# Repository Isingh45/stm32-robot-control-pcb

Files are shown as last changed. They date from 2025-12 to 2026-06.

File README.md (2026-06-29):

# MecaArm Robotic Platform

## Overview

MecaArm is an STM32-based mobile robotic platform developed as the Senior Design Capstone project for **CMPE 492 / CMPE 493** at **California State University, East Bay**.

The platform integrates omnidirectional Mecanum-wheel locomotion, a multi-servo robotic arm, a custom four-layer PCB, embedded firmware, Bluetooth communication, and a mobile application into a complete robotics system.

The project demonstrates end-to-end embedded systems engineering by combining custom hardware design, firmware development, wireless communication, power electronics, and system-level validation.

---

## Technologies

* STM32F429VET6
* ESP32-WROOM-32
* C
* STM32 HAL
* STM32CubeMX
* Bluetooth (UART)
* PWM Motor Control
* Fusion 360 Electronics
* MIT App Inventor
* RT7258 Buck Regulators
* TB6612FNG Motor Drivers

---

## System Architecture

```text
MIT App Inventor Mobile App
             │
        Bluetooth
             │
      ESP32-WROOM-32
             │
      UART (115200 baud)
             │
      STM32F429VET6
      ┌───────────────┐
      │               │
      ▼               ▼
DC Motor Drivers   Servo Control
(TB6612FNG)        (PWM Timers)
      │               │
      ▼               ▼
Mecanum Drive     Robotic Arm
```

---

## Features

* **Custom Four-Layer PCB:** Designed a custom four-layer PCB centered around the STM32F429VET6 microcontroller with dedicated power distribution, motor drivers, communication interfaces, and debugging support.

* **Omnidirectional Mecanum Drive:** Controls four independently driven Mecanum wheels using PWM motor control and dual TB6612FNG motor drivers for omnidirectional robot movement.

* **Robotic Arm Control:** Controls a multi-servo robotic arm using STM32 hardware timers and PWM signals for coordinated actuator movement.

* **Bluetooth Wireless Communication:** Uses an ESP32 as a Bluetooth-to-UART bridge, allowing a custom MIT App Inventor mobile application to wirelessly control the robot.

* **Embedded Firmware:** Developed STM32 firmware using STM32 HAL to manage motor control, servo control, UART communication, and command processing.

* **Multi-Rail Power Architecture:** Designed dedicated power rails for motors, auxiliary peripherals, and logic circuitry to improve electrical stability and isolate high-current motor loads from sensitive electronics.

* **System Integration and Validation:** Successfully demonstrated integrated hardware, firmware, Bluetooth communication, mobile application control, robotic locomotion, and robotic arm operation.

---

## Repository Structure

```text
Documentation/
├── Final Project Report
└── Final Presentation

Hardware/
├── PCB Schematic
├── PCB Layout
├── Fusion 360 Design
├── Bill of Materials
└── Power Budget

Firmware/
├── STM32 Firmware
└── ESP32 Bluetooth Bridge

Mobile-App/
└── MIT App Inventor Application

Validation/
└── System Demonstration Video
```

---

## What I Learned

* Designing custom embedded hardware using a four-layer PCB.
* Developing embedded firmware with STM32 HAL and hardware timers.
* Implementing Bluetooth communication between mobile devices and embedded systems.
* Integrating power electronics, embedded software, wireless communication, and robotic actuators.
* Performing hardware bring-up, debugging, validation, and complete system integration.

---

## Future Improvements

* Add wheel encoder feedback for closed-loop motor control.
* Implement inverse kinematics for robotic arm positioning.
* Integrate ROS 2 for higher-level robot control.
* Add onboard sensors for autonomous navigation.
* Expand the platform with additional perception modules.

---

## Authors

* Inderpal Singh
* Sukhpinder Singh
* Feranmi Falodun
* Pierreline Jacob

**California State University, East Bay**

**CMPE 492 / CMPE 493 – Senior Design Capstone (2025–2026)**

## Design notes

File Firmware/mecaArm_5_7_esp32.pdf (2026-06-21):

#include "BluetoothSerial.h"

#define RXp2 16

#define TXp2 17

BluetoothSerial SerialBT;
String device_name = "ESP32-BT";

void setup() {
SerialBT.begin(device_name); Serial2.begin(115200, SERIAL_8N1, RXp2, TXp2); }

void loop() {
while (SerialBT.available()) {
uint8_t c = SerialBT.read();

// Forward everything from the app to STM32 Serial2.write(c);
}
}

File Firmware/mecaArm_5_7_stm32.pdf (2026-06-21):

/* ============================================================ * STM32F429VIT6 — Combined 4-Wheel Robot + 6-DOF Arm Controller
* ============================================================ *
* MODE SWITCHING:
* Send 'M' to toggle between Robot mode and Arm mode.
* On startup the board is in ROBOT mode.
*
* ── ROBOT MODE (4-wheel drive via TB6612FNG) ──────────────── * Commands (ASCII bytes from ESP32 app):
* F Move forward
* B Move backward
* L Turn left
* R Turn right
* S Stop
*
* Motor PWM: TIM1 (PA8=CH1, PA9=CH2, PA10=CH3, PA11=CH4) * Direction GPIOs:
* Motor 4: PD4 / PD5
* Motor 3: PD2 / PD3
* Motor 1A: PC4 / PC5
* Motor 1B: PD0 / PD1
* STBY: PC0 (HIGH = drivers enabled)
*
* ── ARM MODE (6-DOF servo arm via Hiwonder 500–2500 µs) ───── * Commands (numeric bytes from ESP32 app):
* 1/2 Base rotate right/left
* 3/4 Shoulder up/down
* 5/6 Elbow up/down
* 7/8 Wrist rotate CW/CCW
* 9/10 Wrist pitch up/down * 11/12 Gripper open/close
* 13 | Save current position
* 14 | Reset / stop sequence
* 15 | Run saved sequence
* 16 | Pause (send 15 to resume, 14 to stop)
* H | Home all servos to 1500 µs
* 101–249 Set servo speed (value / 10 = ms per step)
*
* Servo GPIO / Timer mapping:
* ┌────────────┬───────┬───────────┬───────────────────────┐
* │ Servo | │ GPIO │ Timer | │ PCB connector | │
* ├────────────┼───────┼───────────┼───────────────────────┤ * │ Base │ PD12 │ TIM4_CH1 │ LS2 pad pin1=SIGNAL │

* │ Shoulder │ PD13 │ TIM4_CH2 │ LS1 pad pin1=SIGNAL │ * │ Elbow │ PA1 │ TIM2_CH2 │ PH1 hdr pin1=SIGNAL │ * │ Wrist R │ PD14 │ TIM4_CH3 │ JP8 pad pin1=SIGNAL │
* │ Wrist P │ PB15 │ TIM12_CH2 │ LS3 pad pin1=SIGNAL │
* │ Gripper │ PA2 │ TIM2_CH3 │ PH2 hdr pin1=SIGNAL │
* └────────────┴───────┴───────────┴───────────────────────┘ *
* BLUETOOTH: UART7 (PE7=RX, PE8=TX) — 115200 baud
* ============================================================ */

#include "main.h"

#include <stdlib.h>

#include <string.h>

#include <stdio.h>

/* ── Timer / UART handles ─────────────────────────────────── */
TIM_HandleTypeDef htim1; /* Robot motor PWM — TIM1 CH1-CH4 | */
TIM_HandleTypeDef htim2; /* Servo 50 Hz | — PA1(CH2) PA2(CH3) | */
TIM_HandleTypeDef htim4; /* Servo 50 Hz | — PD12(CH1) PD13(CH2) PD14(CH3) */
TIM_HandleTypeDef htim12; /* Servo 50 Hz | — PB15(CH2) | */
UART_HandleTypeDef huart7; /* Bluetooth 115200 baud | */

/* ── Robot defines ───────────────────────────────────────────*/ #define MOTOR_SPEED 750 /* 75 % duty (max = MOTOR_MAX) */
#define MOTOR_MAX 1000 /* matches TIM1 Period = 999 */

/* ── Arm defines ─────────────────────────────────────────────*/ #define SERVO_MIN_US 500
#define SERVO_MAX_US 2500

#define SERVO_MID_US 1500

#define NUM_SERVOS | 6

#define MAX_STEPS | 50

#define SERVO_STEP_SIZE 10

#define S_BASE 0 /* PD12 TIM4_CH1 LS2 pad */ #define S_SHOULDER 1 /* PD13 TIM4_CH2 LS1 pad */ #define S_ELBOW 2 /* PA1 TIM2_CH2 PH1 hdr */ #define S_WRIST_R 3 /* PD14 TIM4_CH3 JP8 pad */

#define S_WRIST_P 4 /* PB15 TIM12_CH2 LS3 pad */

#define S_GRIPPER 5 /* PA2 TIM2_CH3 PH2 hdr */

/* ── Global state ────────────────────────────────────────────*/ typedef enum { MODE_ROBOT = 0, MODE_ARM = 1 } ControlMode;
ControlMode currentMode = MODE_ROBOT;

/* Arm globals */
int32_t servoPos[NUM_SERVOS] = {
SERVO_MID_US, SERVO_MID_US, SERVO_MID_US, SERVO_MID_US, SERVO_MID_US, SERVO_MID_US };
int32_t savedSteps[MAX_STEPS][NUM_SERVOS];
int | stepCount | = 0;
int | speedDelay | = 20;
uint8_t servoPwmStarted = 0;

/* ── Prototypes ──────────────────────────────────────────────*/ void SystemClock_Config(void);
static void MX_GPIO_Init(void);
static void MX_TIM1_Init(void);
static void MX_TIM2_Init(void); static void MX_TIM4_Init(void); static void MX_TIM12_Init(void);
static void MX_UART7_Init(void);

/* Robot */
void Move_Robot(int16_t m4, int16_t m3, int16_t m1a, int16_t m1b); void Stop_Robot(void);

/* Arm */
void Servo_EnablePWM(void);
void Servo_WritePulse(uint8_t id, int32_t pulseUs); void Servo_Step(uint8_t id, int8_t direction);
void Servo_Home(void);
void Run_Sequence(void);

/* Shared */
void UART_Print(const char *msg);
void Print_Mode(void);

/* ============================================================ * MAIN
* ============================================================ */ int main(void)
{
HAL_Init();
SystemClock_Config();

MX_GPIO_Init();

MX_TIM1_Init();
MX_TIM2_Init();
MX_TIM4_Init();
MX_TIM12_Init();
MX_UART7_Init();

/* Start robot motor PWM channels */ HAL_TIM_PWM_Start(&htim1, TIM_CHANNEL_1); HAL_TIM_PWM_Start(&htim1, TIM_CHANNEL_2); HAL_TIM_PWM_Start(&htim1, TIM_CHANNEL_3); HAL_TIM_PWM_Start(&htim1, TIM_CHANNEL_4);

/* Enable TB6612FNG drivers: STBY = PC0 HIGH */ HAL_GPIO_WritePin(GPIOC, GPIO_PIN_0, GPIO_PIN_SET); HAL_Delay(100);

Stop_Robot();

UART_Print("=== MecaArm Controller Ready ===\r\n");
UART_Print("Wheels: F/B/L/R/S | Arm: numeric bytes 1-15 | 0=arm stop | H=home\r\n");

uint8_t rx = 0;
uint8_t armM = 0;
char dbg[64];

while (1)
{
if (HAL_UART_Receive(&huart7, &rx, 1, 10) == HAL_OK) {

sprintf(dbg, "RX: %c (%d)\r\n",
(rx >= 32 && rx < 127) ? rx : '.', rx);
UART_Print(dbg);

HAL_GPIO_TogglePin(GPIOA, GPIO_PIN_5);

/* ===================================================== * ARM STOP: app sends byte 0 on button release
* ===================================================== */ if (rx == 0)
{
armM = 0;
goto loop_end;
}

/* ===================================================== * WHEEL COMMANDS: ASCII bytes from app
* ===================================================== */
if (rx == 'F')
{
Move_Robot(MOTOR_SPEED, MOTOR_SPEED, MOTOR_SPEED, MOTOR_SPEED); armM = 0;
UART_Print("MOVE FORWARD\r\n");
goto loop_end;
}

if (rx == 'B')
{
Move_Robot(-MOTOR_SPEED, -MOTOR_SPEED, -MOTOR_SPEED, -MOTOR_SPEED); armM = 0;
UART_Print("MOVE BACKWARD\r\n");
goto loop_end;
}

if (rx == 'R')
{
Move_Robot(-MOTOR_SPEED, -MOTOR_SPEED, MOTOR_SPEED, MOTOR_SPEED); armM = 0;
UART_Print("TURN RIGHT\r\n");
goto loop_end;
}

if (rx == 'L')
{
Move_Robot(MOTOR_SPEED, MOTOR_SPEED, -MOTOR_SPEED, -MOTOR_SPEED); armM = 0;
UART_Print("TURN LEFT\r\n");
goto loop_end;
}

if (rx == 'S')
{
Stop_Robot();
armM = 0;
UART_Print("STOP\r\n");
goto loop_end;
}

/* ===================================================== * ARM HOME: ASCII H
* ===================================================== */ if (rx == 'H')
{
Servo_EnablePWM();
Servo_Home();
armM = 0;
UART_Print("Servos homed.\r\n");
goto loop_end;
}

/* ===================================================== * SAVE POSITION: raw byte 13
* ===================================================== */ if (rx == 13)
{
Servo_EnablePWM();

if (stepCount < MAX_STEPS)
{
for (int i = 0; i < NUM_SERVOS; i++) savedSteps[stepCount][i] = servoPos[i];

stepCount++;
UART_Print("Position saved.\r\n");
}
else
{
UART_Print("Sequence full.\r\n"); }

armM = 0;
goto loop_end;
}

/* ===================================================== * RESET SEQUENCE: raw byte 14
* ===================================================== */ if (rx == 14)
{
stepCount = 0;
armM = 0;
Stop_Robot();

UART_Print("Sequence reset.\r\n");
goto loop_end;
}

/* ===================================================== * RUN SEQUENCE: raw byte 15
* ===================================================== */ if (rx == 15)
{
Servo_EnablePWM();
Run_Sequence();
armM = 0;
goto loop_end;
}

/* ===================================================== * PAUSE: raw byte 16 or 18 depending on app
* Your app seems to send 18, so accept both.
* ===================================================== */ if (rx == 16 || rx == 18)
{
armM = 0;
UART_Print("Pause command received.\r\n");
goto loop_end;
}

/* ===================================================== * SPEED: raw bytes 101-249
* ===================================================== */ if (rx >= 101 && rx <= 249)
{
speedDelay = rx / 10;
sprintf(dbg, "Speed set: %d ms/step\r\n", speedDelay); UART_Print(dbg);
armM = 0;
goto loop_end;
}

/* ===================================================== * ARM MOVEMENT: raw numeric bytes 1-12
* ===================================================== */ if (rx >= 1 && rx <= 12)
{
armM = rx;

Servo_EnablePWM();
goto loop_end;
}
}

loop_end:

/* Continuous arm movement while app button is held */ switch (armM)
{
case 1:
Servo_Step(S_BASE, +1);
HAL_Delay(speedDelay);
break;

case 2:
Servo_Step(S_BASE, -1);
HAL_Delay(speedDelay);
break;

case 3:
Servo_Step(S_SHOULDER, +1); HAL_Delay(speedDelay);
break;

case 4:
Servo_Step(S_SHOULDER, -1); HAL_Delay(speedDelay);
break;

case 5:
Servo_Step(S_ELBOW, +1);
HAL_Delay(speedDelay);
break;

case 6:
Servo_Step(S_ELBOW, -1);
HAL_Delay(speedDelay);
break;

case 7:
Servo_Step(S_WRIST_R, +1); HAL_Delay(speedDelay);
break;

case 8:
Servo_Step(S_WRIST_R, -1); HAL_Delay(speedDelay);
break;

case 9:
Servo_Step(S_WRIST_P, +1); HAL_Delay(speedDelay);
break;

case 10:
Servo_Step(S_WRIST_P, -1); HAL_Delay(speedDelay);
break;

case 11:
Servo_Step(S_GRIPPER, +1); HAL_Delay(speedDelay);
break;

case 12:
Servo_Step(S_GRIPPER, -1); HAL_Delay(speedDelay);
break;

default:
break;
}
}
}

/* ============================================================ * ROBOT MOTOR CONTROL
* ============================================================ */ void Move_Robot(int16_t m4, int16_t m3, int16_t m1a, int16_t m1b)
{
/* Motor 4 — PD4/PD5 direction, TIM1_CH1 speed */
HAL_GPIO_WritePin(GPIOD, GPIO_PIN_4, (m4 >= 0) ? GPIO_PIN_SET : GPIO_PIN_RESET);
HAL_GPIO_WritePin(GPIOD, GPIO_PIN_5, (m4 >= 0) ? GPIO_PIN_RESET : GPIO_PIN_SET);
__HAL_TIM_SET_COMPARE(&htim1, TIM_CHANNEL_1, (uint32_t)abs(m4));

/* Motor 3 — PD2/PD3 direction, TIM1_CH2 speed */ HAL_GPIO_WritePin(GPIOD, GPIO_PIN_2, (m3 >= 0) ? GPIO_PIN_SET : GPIO_PIN_RESET);
HAL_GPIO_WritePin(GPIOD, GPIO_PIN_3, (m3 >= 0) ? GPIO_PIN_RESET : GPIO_PIN_SET);
__HAL_TIM_SET_COMPARE(&htim1, TIM_CHANNEL_2, (uint32_t)abs(m3));

/* Motor 1A — PC4/PC5 direction, TIM1_CH3 speed */ HAL_GPIO_WritePin(GPIOC, GPIO_PIN_4, (m1a >= 0) ? GPIO_PIN_SET : GPIO_PIN_RESET);
HAL_GPIO_WritePin(GPIOC, GPIO_PIN_5, (m1a >= 0) ? GPIO_PIN_RESET : GPIO_PIN_SET);
__HAL_TIM_SET_COMPARE(&htim1, TIM_CHANNEL_3, (uint32_t)abs(m1a));

/* Motor 1B — PD0/PD1 direction, TIM1_CH4 speed */ HAL_GPIO_WritePin(GPIOD, GPIO_PIN_0, (m1b >= 0) ? GPIO_PIN_SET : GPIO_PIN_RESET);
HAL_GPIO_WritePin(GPIOD, GPIO_PIN_1, (m1b >= 0) ? GPIO_PIN_RESET : GPIO_PIN_SET);
__HAL_TIM_SET_COMPARE(&htim1, TIM_CHANNEL_4, (uint32_t)abs(m1b)); }

void Stop_Robot(void)
{
Move_Robot(0, 0, 0, 0);
}

/* ============================================================ * SERVO / ARM CONTROL
* ============================================================ */ void Servo_EnablePWM(void)
{
if (servoPwmStarted) return;

HAL_TIM_PWM_Start(&htim2, TIM_CHANNEL_2); /* PA1 Elbow */ HAL_TIM_PWM_Start(&htim2, TIM_CHANNEL_3); /* PA2 Gripper */ HAL_TIM_PWM_Start(&htim4, TIM_CHANNEL_1); /* PD12 Base */ HAL_TIM_PWM_Start(&htim4, TIM_CHANNEL_2); /* PD13 Shoulder */ HAL_TIM_PWM_Start(&htim4, TIM_CHANNEL_3); /* PD14 Wrist R */ HAL_TIM_PWM_Start(&htim12, TIM_CHANNEL_2); /* PB15 Wrist P */

servoPwmStarted = 1;
}

/**
* @brief Write pulse width in microseconds to one servo.
* | Timer clock = 1 MHz (PSC=15 at 16 MHz HSI)
* | → 1 tick = 1 µs → CCR = pulseUs directly.
* | Clamped to Hiwonder range 500–2500 µs.
*/
void Servo_WritePulse(uint8_t id, int32_t pulseUs) {
if (id >= NUM_SERVOS) return;
Servo_EnablePWM();

if (pulseUs < SERVO_MIN_US) pulseUs = SERVO_MIN_US; if (pulseUs > SERVO_MAX_US) pulseUs = SERVO_MAX_US; servoPos[id] = pulseUs;

switch (id)
{
case S_BASE: __HAL_TIM_SET_COMPARE(&htim4, TIM_CHANNEL_1, (uint32_t)pulseUs); break;
case S_SHOULDER: __HAL_TIM_SET_COMPARE(&htim4, TIM_CHANNEL_2, (uint32_t)pulseUs); break;
case S_ELBOW: __HAL_TIM_SET_COMPARE(&htim2, TIM_CHANNEL_2, (uint32_t)pulseUs); break;
case S_WRIST_R: __HAL_TIM_SET_COMPARE(&htim4, TIM_CHANNEL_3, (uint32_t)pulseUs); break;
case S_WRIST_P: __HAL_TIM_SET_COMPARE(&htim12, TIM_CHANNEL_2, (uint32_t)pulseUs); break;
case S_GRIPPER: __HAL_TIM_SET_COMPARE(&htim2, TIM_CHANNEL_3, (uint32_t)pulseUs); break;
default: break;
}
}

void Servo_Step(uint8_t id, int8_t direction)
{
Servo_WritePulse(id, servoPos[id] + (direction * SERVO_STEP_SIZE)); }

void Servo_Home(void)
{
Servo_WritePulse(S_BASE, SERVO_MID_US); Servo_WritePulse(S_SHOULDER, SERVO_MID_US); Servo_WritePulse(S_ELBOW, SERVO_MID_US); Servo_WritePulse(S_WRIST_R, SERVO_MID_US);

Servo_WritePulse(S_WRIST_P, SERVO_MID_US); Servo_WritePulse(S_GRIPPER, SERVO_MID_US); }

/**
* @brief Play back saved positions.
* Byte 14 = stop, byte 16 = pause (byte 15 resumes). */
void Run_Sequence(void)
{
if (stepCount < 2)
{
UART_Print("Need at least 2 saved positions.\r\n"); return;
}

UART_Print("Running sequence. Send 14 to stop.\r\n");

uint8_t rx = 0;
uint8_t running = 1;

while (running)
{
for (int i = 0; i < stepCount - 1 && running; i++)
{
if (HAL_UART_Receive(&huart7, &rx, 1, 1) == HAL_OK) {
if (rx == 14) { running = 0; break; }
if (rx == 16)
{
UART_Print("Paused. Send 15 to resume.\r\n"); while (rx != 15 && rx != 14) HAL_UART_Receive(&huart7, &rx, 1, 100); if (rx == 14) { running = 0; break; } UART_Print("Resumed.\r\n");
}
}

for (uint8_t s = 0; s < NUM_SERVOS && running; s++) {
int32_t from = savedSteps[i][s];
int32_t to = savedSteps[i + 1][s];
if (from == to) continue;

int8_t dir = (to > from) ? 1 : -1;
for (int32_t pos = from; pos != to; pos += dir) {
Servo_WritePulse(s, pos);
HAL_Delay(speedDelay);
if (HAL_UART_Receive(&huart7, &rx, 1, 1) == HAL_OK && rx == 14) { running = 0; break; }
}
}
}
}

UART_Print("Sequence stopped.\r\n");
}

/* ============================================================ * SHARED HELPERS
* ============================================================ */ void UART_Print(const char *msg)
{
HAL_UART_Transmit(&huart7, (uint8_t *)msg, strlen(msg), 100);
}

void Print_Mode(void)
{
if (currentMode == MODE_ROBOT)
UART_Print("-- ROBOT MODE -- (F/B/L/R/S | 'M' to switch)\r\n");
else
UART_Print("-- ARM MODE -- (1-12=move 13=save 14=reset 15=run H=home | 'M' to
switch)\r\n");
}

/**
* @brief System Clock Configuration * @retval None
*/
void SystemClock_Config(void)
{
RCC_OscInitTypeDef RCC_OscInitStruct = {0}; RCC_ClkInitTypeDef RCC_ClkInitStruct = {0};

/** Configure the main internal regulator output voltage */
__HAL_RCC_PWR_CLK_ENABLE();

__HAL_PWR_VOLTAGESCALING_CONFIG(PWR_REGULATOR_VOLTAGE_SCALE3);

/** Initializes the RCC Oscillators according to the specified parameters
* in the RCC_OscInitTypeDef structure.
*/
RCC_OscInitStruct.OscillatorType = RCC_OSCILLATORTYPE_HSI; RCC_OscInitStruct.HSIState = RCC_HSI_ON; RCC_OscInitStruct.HSICalibrationValue = RCC_HSICALIBRATION_DEFAULT; RCC_OscInitStruct.PLL.PLLState = RCC_PLL_NONE;
if (HAL_RCC_OscConfig(&RCC_OscInitStruct) != HAL_OK)
{
Error_Handler();
}

/** Initializes the CPU, AHB and APB buses clocks
*/
RCC_ClkInitStruct.ClockType = RCC_CLOCKTYPE_HCLK|RCC_CLOCKTYPE_SYSCLK |RCC_CLOCKTYPE_PCLK1|RCC_CLOCKTYPE_PCLK2; RCC_ClkInitStruct.SYSCLKSource = RCC_SYSCLKSOURCE_HSI; RCC_ClkInitStruct.AHBCLKDivider = RCC_SYSCLK_DIV1; RCC_ClkInitStruct.APB1CLKDivider = RCC_HCLK_DIV1; RCC_ClkInitStruct.APB2CLKDivider = RCC_HCLK_DIV1;

if (HAL_RCC_ClockConfig(&RCC_ClkInitStruct, FLASH_LATENCY_0) != HAL_OK) {
Error_Handler();
}
}

/**
* @brief TIM1 Initialization Function * @param None
* @retval None
*/
static void MX_TIM1_Init(void)
{

/* USER CODE BEGIN TIM1_Init 0 */

/* USER CODE END TIM1_Init 0 */

TIM_ClockConfigTypeDef sClockSourceConfig = {0}; TIM_MasterConfigTypeDef sMasterConfig = {0}; TIM_OC_InitTypeDef sConfigOC = {0};

TIM_BreakDeadTimeConfigTypeDef sBreakDeadTimeConfig = {0};

/* USER CODE BEGIN TIM1_Init 1 */

/* USER CODE END TIM1_Init 1 */
htim1.Instance = TIM1;
htim1.Init.Prescaler = 179;
htim1.Init.CounterMode = TIM_COUNTERMODE_UP; htim1.Init.Period = 999;
htim1.Init.ClockDivision = TIM_CLOCKDIVISION_DIV1; htim1.Init.RepetitionCounter = 0;
htim1.Init.AutoReloadPreload = TIM_AUTORELOAD_PRELOAD_ENABLE; if (HAL_TIM_Base_Init(&htim1) != HAL_OK)
{
Error_Handler();
}
sClockSourceConfig.ClockSource = TIM_CLOCKSOURCE_INTERNAL;
if (HAL_TIM_ConfigClockSource(&htim1, &sClockSourceConfig) != HAL_OK) {
Error_Handler();
}
if (HAL_TIM_PWM_Init(&htim1) != HAL_OK) {
Error_Handler();
}
sMasterConfig.MasterOutputTrigger = TIM_TRGO_RESET; sMasterConfig.MasterSlaveMode = TIM_MASTERSLAVEMODE_DISABLE;
if (HAL_TIMEx_MasterConfigSynchronization(&htim1, &sMasterConfig) != HAL_OK) {
Error_Handler();
}
sConfigOC.OCMode = TIM_OCMODE_PWM1; sConfigOC.Pulse = 0;
sConfigOC.OCPolarity = TIM_OCPOLARITY_HIGH; sConfigOC.OCNPolarity = TIM_OCNPOLARITY_HIGH; sConfigOC.OCFastMode = TIM_OCFAST_DISABLE;
sConfigOC.OCIdleState = TIM_OCIDLESTATE_RESET;
sConfigOC.OCNIdleState = TIM_OCNIDLESTATE_RESET;
if (HAL_TIM_PWM_ConfigChannel(&htim1, &sConfigOC, TIM_CHANNEL_1) != HAL_OK) {
Error_Handler();
}
if (HAL_TIM_PWM_ConfigChannel(&htim1, &sConfigOC, TIM_CHANNEL_2) != HAL_OK) {

Error_Handler();
}
if (HAL_TIM_PWM_ConfigChannel(&htim1, &sConfigOC, TIM_CHANNEL_3) != HAL_OK) {
Error_Handler();
}
if (HAL_TIM_PWM_ConfigChannel(&htim1, &sConfigOC, TIM_CHANNEL_4) != HAL_OK) {
Error_Handler();
}
sBreakDeadTimeConfig.OffStateRunMode = TIM_OSSR_DISABLE; sBreakDeadTimeConfig.OffStateIDLEMode = TIM_OSSI_DISABLE; sBreakDeadTimeConfig.LockLevel = TIM_LOCKLEVEL_OFF; sBreakDeadTimeConfig.DeadTime = 0;
sBreakDeadTimeConfig.BreakState = TIM_BREAK_DISABLE; sBreakDeadTimeConfig.BreakPolarity = TIM_BREAKPOLARITY_HIGH; sBreakDeadTimeConfig.AutomaticOutput = TIM_AUTOMATICOUTPUT_DISABLE; if (HAL_TIMEx_ConfigBreakDeadTime(&htim1, &sBreakDeadTimeConfig) != HAL_OK) {
Error_Handler();
}
/* USER CODE BEGIN TIM1_Init 2 */

/* USER CODE END TIM1_Init 2 */ HAL_TIM_MspPostInit(&htim1);

}

/**
* @brief TIM2 Initialization Function * @param None
* @retval None
*/
static void MX_TIM2_Init(void)
{

/* USER CODE BEGIN TIM2_Init 0 */

/* USER CODE END TIM2_Init 0 */

TIM_MasterConfigTypeDef sMasterConfig = {0}; TIM_OC_InitTypeDef sConfigOC = {0};

/* USER CODE BEGIN TIM2_Init 1 */

/* USER CODE END TIM2_Init 1 */
htim2.Instance = TIM2;
htim2.Init.Prescaler = 15;
htim2.Init.CounterMode = TIM_COUNTERMODE_UP; htim2.Init.Period = 19999;
htim2.Init.ClockDivision = TIM_CLOCKDIVISION_DIV1; htim2.Init.AutoReloadPreload = TIM_AUTORELOAD_PRELOAD_DISABLE; if (HAL_TIM_PWM_Init(&htim2) != HAL_OK)
{
Error_Handler();
}
sMasterConfig.MasterOutputTrigger = TIM_TRGO_RESET; sMasterConfig.MasterSlaveMode = TIM_MASTERSLAVEMODE_DISABLE;
if (HAL_TIMEx_MasterConfigSynchronization(&htim2, &sMasterConfig) != HAL_OK) {
Error_Handler();
}
sConfigOC.OCMode = TIM_OCMODE_PWM1; sConfigOC.Pulse = 0;
sConfigOC.OCPolarity = TIM_OCPOLARITY_HIGH;
sConfigOC.OCFastMode = TIM_OCFAST_DISABLE;
if (HAL_TIM_PWM_ConfigChannel(&htim2, &sConfigOC, TIM_CHANNEL_2) != HAL_OK) {
Error_Handler();
}
if (HAL_TIM_PWM_ConfigChannel(&htim2, &sConfigOC, TIM_CHANNEL_3) != HAL_OK) {
Error_Handler();
}
/* USER CODE BEGIN TIM2_Init 2 */

/* USER CODE END TIM2_Init 2 */ HAL_TIM_MspPostInit(&htim2);

}

/**
* @brief TIM4 Initialization Function * @param None
* @retval None
*/
static void MX_TIM4_Init(void) {

/* USER CODE BEGIN TIM4_Init 0 */

/* USER CODE END TIM4_Init 0 */

TIM_ClockConfigTypeDef sClockSourceConfig = {0}; TIM_MasterConfigTypeDef sMasterConfig = {0}; TIM_OC_InitTypeDef sConfigOC = {0};

/* USER CODE BEGIN TIM4_Init 1 */

/* USER CODE END TIM4_Init 1 */
htim4.Instance = TIM4;
htim4.Init.Prescaler = 15;
htim4.Init.CounterMode = TIM_COUNTERMODE_UP; htim4.Init.Period = 19999;
htim4.Init.ClockDivision = TIM_CLOCKDIVISION_DIV1; htim4.Init.AutoReloadPreload = TIM_AUTORELOAD_PRELOAD_DISABLE; if (HAL_TIM_Base_Init(&htim4) != HAL_OK)
{
Error_Handler();
}
sClockSourceConfig.ClockSource = TIM_CLOCKSOURCE_INTERNAL;
if (HAL_TIM_ConfigClockSource(&htim4, &sClockSourceConfig) != HAL_OK) {
Error_Handler();
}
if (HAL_TIM_PWM_Init(&htim4) != HAL_OK) {
Error_Handler();
}
sMasterConfig.MasterOutputTrigger = TIM_TRGO_RESET; sMasterConfig.MasterSlaveMode = TIM_MASTERSLAVEMODE_DISABLE;
if (HAL_TIMEx_MasterConfigSynchronization(&htim4, &sMasterConfig) != HAL_OK) {
Error_Handler();
}
sConfigOC.OCMode = TIM_OCMODE_PWM1; sConfigOC.Pulse = 0;
sConfigOC.OCPolarity = TIM_OCPOLARITY_HIGH;
sConfigOC.OCFastMode = TIM_OCFAST_DISABLE;
if (HAL_TIM_PWM_ConfigChannel(&htim4, &sConfigOC, TIM_CHANNEL_1) != HAL_OK) {
Error_Handler();

}
if (HAL_TIM_PWM_ConfigChannel(&htim4, &sConfigOC, TIM_CHANNEL_2) != HAL_OK) {
Error_Handler();
}
if (HAL_TIM_PWM_ConfigChannel(&htim4, &sConfigOC, TIM_CHANNEL_3) != HAL_OK) {
Error_Handler();
}
/* USER CODE BEGIN TIM4_Init 2 */

/* USER CODE END TIM4_Init 2 */ HAL_TIM_MspPostInit(&htim4);

}

/**
* @brief TIM12 Initialization Function * @param None
* @retval None
*/
static void MX_TIM12_Init(void)
{

/* USER CODE BEGIN TIM12_Init 0 */

/* USER CODE END TIM12_Init 0 */

TIM_OC_InitTypeDef sConfigOC = {0};

/* USER CODE BEGIN TIM12_Init 1 */

/* USER CODE END TIM12_Init 1 */ htim12.Instance = TIM12;
htim12.Init.Prescaler = 15;
htim12.Init.CounterMode = TIM_COUNTERMODE_UP; htim12.Init.Period = 19999;
htim12.Init.ClockDivision = TIM_CLOCKDIVISION_DIV1; htim12.Init.AutoReloadPreload = TIM_AUTORELOAD_PRELOAD_DISABLE; if (HAL_TIM_PWM_Init(&htim12) != HAL_OK)
{
Error_Handler();
}
sConfigOC.OCMode = TIM_OCMODE_PWM1;

sConfigOC.Pulse = 0;
sConfigOC.OCPolarity = TIM_OCPOLARITY_HIGH;
sConfigOC.OCFastMode = TIM_OCFAST_DISABLE;
if (HAL_TIM_PWM_ConfigChannel(&htim12, &sConfigOC, TIM_CHANNEL_2) != HAL_OK) {
Error_Handler();
}
/* USER CODE BEGIN TIM12_Init 2 */

/* USER CODE END TIM12_Init 2 */ HAL_TIM_MspPostInit(&htim12);

}

/**
* @brief UART7 Initialization Function * @param None
* @retval None
*/
static void MX_UART7_Init(void)
{

/* USER CODE BEGIN UART7_Init 0 */

/* USER CODE END UART7_Init 0 */

/* USER CODE BEGIN UART7_Init 1 */

/* USER CODE END UART7_Init 1 */ huart7.Instance = UART7;
huart7.Init.BaudRate = 115200; huart7.Init.WordLength = UART_WORDLENGTH_8B; huart7.Init.StopBits = UART_STOPBITS_1; huart7.Init.Parity = UART_PARITY_NONE; huart7.Init.Mode = UART_MODE_TX_RX; huart7.Init.HwFlowCtl = UART_HWCONTROL_NONE; huart7.Init.OverSampling = UART_OVERSAMPLING_16; if (HAL_UART_Init(&huart7) != HAL_OK)
{
Error_Handler();
}
/* USER CODE BEGIN UART7_Init 2 */

/* USER CODE END UART7_Init 2 */

}

/**
* @brief GPIO Initialization Function * @param None
* @retval None
*/
static void MX_GPIO_Init(void)
{
GPIO_InitTypeDef GPIO_InitStruct = {0}; /* USER CODE BEGIN MX_GPIO_Init_1 */

/* USER CODE END MX_GPIO_Init_1 */

/* GPIO Ports Clock Enable */ __HAL_RCC_GPIOC_CLK_ENABLE(); __HAL_RCC_GPIOA_CLK_ENABLE(); __HAL_RCC_GPIOE_CLK_ENABLE(); __HAL_RCC_GPIOB_CLK_ENABLE();
__HAL_RCC_GPIOD_CLK_ENABLE();

/*Configure GPIO pin Output Level */
HAL_GPIO_WritePin(GPIOC, GPIO_PIN_0|GPIO_PIN_4|GPIO_PIN_5, GPIO_PIN_RESET);

/*Configure GPIO pin Output Level */
HAL_GPIO_WritePin(GPIOA, GPIO_PIN_5, GPIO_PIN_RESET);

/*Configure GPIO pin Output Level */
HAL_GPIO_WritePin(GPIOD, GPIO_PIN_0|GPIO_PIN_1|GPIO_PIN_2|GPIO_PIN_3 |GPIO_PIN_4|GPIO_PIN_5, GPIO_PIN_RESET);

/*Configure GPIO pins : PC0 PC4 PC5 */
GPIO_InitStruct.Pin = GPIO_PIN_0|GPIO_PIN_4|GPIO_PIN_5; GPIO_InitStruct.Mode = GPIO_MODE_OUTPUT_PP; GPIO_InitStruct.Pull = GPIO_NOPULL; GPIO_InitStruct.Speed = GPIO_SPEED_FREQ_LOW; HAL_GPIO_Init(GPIOC, &GPIO_InitStruct);

/*Configure GPIO pin : PA5 */
GPIO_InitStruct.Pin = GPIO_PIN_5; GPIO_InitStruct.Mode = GPIO_MODE_OUTPUT_PP; GPIO_InitStruct.Pull = GPIO_NOPULL; GPIO_InitStruct.Speed = GPIO_SPEED_FREQ_LOW;

HAL_GPIO_Init(GPIOA, &GPIO_InitStruct);

/*Configure GPIO pins : PD0 PD1 PD2 PD3
PD4 PD5 */
GPIO_InitStruct.Pin = GPIO_PIN_0|GPIO_PIN_1|GPIO_PIN_2|GPIO_PIN_3 |GPIO_PIN_4|GPIO_PIN_5;
GPIO_InitStruct.Mode = GPIO_MODE_OUTPUT_PP; GPIO_InitStruct.Pull = GPIO_NOPULL;
GPIO_InitStruct.Speed = GPIO_SPEED_FREQ_LOW; HAL_GPIO_Init(GPIOD, &GPIO_InitStruct);

/* USER CODE BEGIN MX_GPIO_Init_2 */

/* USER CODE END MX_GPIO_Init_2 */ }

/* USER CODE BEGIN 4 */

/* USER CODE END 4 */

/**
* @brief This function is executed in case of error occurrence. * @retval None
*/
void Error_Handler(void)
{
/* USER CODE BEGIN Error_Handler_Debug */
/* User can add his own implementation to report the HAL error return state */ __disable_irq();
while (1)
{
}
/* USER CODE END Error_Handler_Debug */ }
#ifdef USE_FULL_ASSERT

/**
* @brief Reports the name of the source file and the source line number * where the assert_param error has occurred.
* @param file: pointer to the source file name
* @param line: assert_param error line source number
* @retval None
*/
void assert_failed(uint8_t *file, uint32_t line)
{

/* USER CODE BEGIN 6 */
/* User can add his own implementation to report the file name and line number, ex: printf("Wrong parameters value: file %s on line %d\r\n", file, line) */
/* USER CODE END 6 */
}
#endif /* USE_FULL_ASSERT */

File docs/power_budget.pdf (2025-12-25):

Electrical Inputs | Temperature | Power + Efficiency | Noise / Ripple Design | Passive Components | Protection / Documentation Component | Pins | Function / Role | Source Rail Output Rail | V_in (V) | V_out (V) | I_typ (mA) | I_peak in (mA) trace_in | trace_in | I_peak out (mA) | trace_out Duty (%) | P_out (mW) | η (%) | P_in (mW) | P_loss (mW) | Noise Sensitivity Allowed Ripple/Noise (mVpp) | Est. Ripple (mVpp) | Post-Filter Type | Local Capacitance (F) | Resistors (Ω) | Inductance (H) | Protection | Notes | Datasheet | Design | Distributor Zeee 2S Lipo Battery 2200mAh 7.4V
50C Shorty Pack Battery with XT60 Connector | Main power source | BAT_7.4V | - | - | 7.4 V | - | 150 mil | 948 mil | - | - | - | - | - | - | - | - | - | - | - | - | -

Two 3.7 V 1800 mAh
Li-ion cells in series. Typical 1C continuous discharge, 2C peak. | you need connector on
your board | Hiwonder

LFD-218 servo

Signal Wire Positive pole of power supply Ground Wire | High-torque PWM digital servo for arm joints | BAT_7.4V | - | 7.4V | - | 100 mA | 75 mil | 181 mil | - | - | - | - | - | - | -

Full-metal digital servo for arm joints. No-load 100 mA. Locked-rotor (stall) 2.4–3 A. Works from 2S

Li-ion/LiPo rail. PWM
signal from MCU, high
current drawn from battery
rail. | Hiwonder
LD-1501MG servo | White WireSignal input Red WireConnect to 7.4 V

Black WireConnect to ground

High-precision PWM digital servo
(used for base / shoulder / elbow
joints) | BAT_7.4V | - | 7.4V | - | 100 mA | 75 mil | 181 mil | - | - | - | - | - | - | -

Metal-gear servo. Working
voltage 6–8.4 V. No-load
100 mA. Stall 2.4–3 A. PWM control. Used for precise joints. | Hiwonder Buck 5V(RT7258) | Step-down buck: BAT_7.4V →
Buck_5V rail for 5 V loads | BAT_7.4V | Buck_5V | BAT_7.4V | 5 V | - | 60 mil | 256 mil | 60 mil | 380 mil | - | 25.75 W | 90 % | 28.611 W | 2.861W

TT Motor 1

1 pin for power another to ground | Drive motor (Mecanum wheel) | Buck_5V | - | 5V | - | 100 mA (assumpton) | - | 51 mil | - | - | - | - | - | - | -

Ratio 1:42, Weight 30 g, Speed 150 RPM, Size

63×22×19 mm, Works with TurboPi/MasterPi/GoGoPi/ 4WD

TT Motor 2 | Drive motor (Mecanum wheel) | Buck_5V | - | 5V | - | - | - | 51 mil | - | - | - | - | - | - | -

Ratio 1:42, Weight 30 g, Speed 150 RPM, Size

63×22×19 mm, Works with TurboPi/MasterPi/GoGoPi/ 4WD

TT Motor 3 | Drive motor (Mecanum wheel) | Buck_5V | - | 5V | - | - | - | 51 mil | - | - | - | - | - | - | -

Ratio 1:42, Weight 30 g, Speed 150 RPM, Size

63×22×19 mm, Works with TurboPi/MasterPi/GoGoPi/ 4WD

TT Motor 4 | Drive motor (Mecanum wheel) | Buck_5V | - | 5V | - | - | - | 51 mil | - | - | - | - | - | - | -

Ratio 1:42, Weight 30 g, Speed 150 RPM, Size

63×22×19 mm, Works with TurboPi/MasterPi/GoGoPi/ 4WD Motor Driver ICs 1 VM | Input to Motor | Buck_5V | - | - | - | - | - | - | -
Motor Driver ICs 1 VM1 | - | - | 5V | - | - | 23 mil | 30 mil | - | - | - | - | - | - | -

You feed VM = 12 V from
your battery through the
power distribution tree to
actually spin the DC motors. Motor Driver ICs 1 VM2 | - | 23 mil | 30 mil | - | - | - | - | - | - | - Motor Driver ICs 1 VM3 | - | 23 mil | 30 mil | - | - | - | - | - | - | - Motor Driver ICs 2 VM | Buck_5V | - | - | - | - | - | - | - Motor Driver ICs 2 VM1 | - | 23 mil | 30 mil | - | - | - | - | - | - | - Motor Driver ICs 2 VM2 | - | 23mil | 30 mil | - | - | - | - | - | - | - Motor Driver ICs 2 VM3 | - | 23 mil | 30 mil | - | - | - | - | - | - | - Motor Driver ICs 1 Channel A | Output to Motor 1 | - | - | - | - | - | - | 1.2 A | 22 mil | 51 mil | - | - | - | - | - Motor Driver ICs 1 Channel B | Output to Motor 2 | - | - | - | - | - | - | 1.2 A | 22 mil | 51 mil | - | - | - | - | - Motor Driver ICs 2 Channel A | Output to Motor 3 | - | - | - | - | - | - | 1.2 A | 22 mil | 51 mil | - | - | - | - | - Motor Driver ICs 2 Channel B | Output to Motor 4 | - | - | - | - | - | - | 1.2 A | 22 mil | 51 mil | - | - | - | - | - Cooling Fan Service
1 pin for power another to ground | Buck_5V | - | 5V | - | - | - | 10 mil | - | - | - | - | - | - | - | - Buck 5V(RT7258)_2 | Step-down buck: BAT_7.4V →
Buck_5V rail for 5 V loads | BAT_7.4V | Buck_5V | BAT_7.4V | 5 V | - | 41 mil | 78 mil | 56 mil | 88 mil | - | 11.828 W | 90 % | 10.645W | 1.183 W

Ultrasonic Distance Sensor

Pin | Description
5V | Power input GND | Ground cable SDA | SDA data cable SCL | SCL clock cable
I²C ultrasonic distance sensor with RGB indicator for obstacle
detection | Buck_5V | - | 5V | - | 2 mA | 6 mil | - | - | - Red Wire: Positive pole of power supply (VCC) Brown/Black Wire: Ground wire

(GND) Orange/Yellow Wire: Signal wire

(PWM input)
- | Buck_5V | - | 5V | - | 50 mA | 25 mil | - | - | -

Rotate speed 0.12 s/60° @ 4.8 V, 0.10 s/60° @ 6 V; Locked torque 1.5 kg·cm @ 4.8 V / 1.8 kg·cm @ 6 V; Weight 14 g; PWM

pulse 500–2500 µs
(0–180°) | Hiwonder

Small digital servo for robotic
joints; PWM-controlled; draws 50 mA typical, up to 700 mA when
stalled. | Buck_5V | - | 5V | - | 50 mA | 25 mil | - | - | -

Rotate speed 0.12 s/60° @ 4.8 V, 0.10 s/60° @ 6 V; Locked torque 1.5 kg·cm @ 4.8 V / 1.8 kg·cm @ 6 V; Weight 14 g; PWM

pulse 500–2500 µs
(0–180°) | Hiwonder
- | Buck_5V | - | 5V | - | 50 mA | 25 mil | - | - | -

Rotate speed 0.12 s/60° @ 4.8 V, 0.10 s/60° @ 6 V; Locked torque 1.5 kg·cm @ 4.8 V / 1.8 kg·cm @ 6 V; Weight 14 g; PWM

pulse 500–2500 µs
(0–180°) | Hiwonder USB-UART Bridge (FT232R): VCC | Buck_5V | - | 5V | - | 15 mA | 6 mil | - | - | - | - | - | - | - | - | - | - | - | - | - | - | -
Buzzers | Driven by PB8 through NPN
transistor
Audio alert device for robot status/warnings (startup beeps, error alerts). | Buck5V2 | - | Buck5V_2 | - | - | 6mil | -

Buck 3V3 (AP63357)

Buck 5V(RT7258) _2 | Buck_3.3V | 5V | 3.3 V | 18 mil | 21 mil | 27 mil | 2.443W | 90% 2.174W | 0.271W

MCU (STM32F427xx)

Main system microcontroller that runs the robot’s control logic, sensor processing, communication interfaces, and

actuator commands. | Buck_3.3V | - | 3.3 V | - | - | - | - | - | - | - | - MCU:VDD | Main 3.3 V digital power for MCU

core and I/O (total of all VDD
pins) | - | - | - | - | - | 270 mA | 7 mil | - | - | - | - MCU:VDD1 | - | - | - | - | - | - | 6 mil | - | - | - | - | VDD1 C_7 = 100 nF MCU:VDD2 | - | - | - | - | - | - | 6 mil | - | - | - | - | VDD2 C_8 = 100 nF MCU:VDD3 | - | - | - | - | - | - | 6 mil | - | - | - | - | VDD3 C_9 = 100 nF MCU:VDD4 | - | - | - | - | - | - | 6 mil | - | - | - | - | VDD4 C_10 = 100 nF MCU:VDD5 | - | - | - | - | - | - | 6 mil | - | - | - | - | VDD5 C_11 = 100 nF MCU:VDD6 | - | - | - | - | - | - | 6 mil | - | - | - | - | VDD6 C_12 = 100 nF MCU:VDDA | - | - | - | - | - | 1.6 mA | 6 mil | - | - | - | - | VDDA C_13 = 100 nF MCU:VREF+ | Analog reference input that sets
full-scale range for the ADC | - | - | - | - | 300 uA | 6 mil | - | - | - | -

VREF+ C_14 = 100 nF

+ C_15 = 1 uF MCU:VBAT
Backup supply for RTC and
backup registers when main 3.3 V
is off | - | - | - | - | 1 uA | 6 mil | - | - | - | - | - MCU:VCAP1
Internal 1.2 V core regulator output – decoupling cap only | - | - | - | - | - | - | - | - | - | - | - | VCAP1 C_16 = 2.2 uF MCU:VCAP2
Internal 1.2 V core regulator output – decoupling cap only | - | - | - | - | - | - | - | - | - | - | VCAP2 C_17 = 2.2 uF GPIO_PIN | - | - | - | - | - | - | 8mA | - | - | 20 mA CHANZON Led (G/B) | PA5/PB0 | - | MCU_3.3V | 3.1 V | - | 20 mA CHANZON Led (R) | ? | PA3 | - | MCU_3.3V | 2.1 V | - | 20 mA | Link

Motor Driver ICs 1 VCC

Logic supply for input signal detection, internal H-bridge

control, standby logic | Buck_3.3V | - | 3.3 V | - | 1.1 mA | 6 mil | - | - | - | - | - | - | - | - | - | - | -

VCC

C_5=10uF C_6= 0.1uF

You feed VCC = 3.3 V
from the STM32F429 logic
rail (so PWM, DIR, and STBY pins all see 3.3 V

logic levels).

Motor Driver ICs 2 VCC | Buck_3.3V | - | 3.3 V | - | 1.1 mA | 6 mil | - | - | - | - | - | - | - | - | - | - | -

VCC

C_5=10uF C_6= 0.1uF

You feed VCC = 3.3 V
from the STM32F429 logic
rail (so PWM, DIR, and STBY pins all see 3.3 V

logic levels).

USB-UART Bridge (FT232R) | USB-to-UART interface for programming / debug | - | - | - | - | - | - | - | - | - | - | - | - | - | - | - | - | -

VCC

C_1=100nF C_2=100nF C_3=4.7uF

3V3 out C_4 = 100 nF

Pin 1 USB R_1 =4k7 R_2 =10k

- | - | USB powered only. Not
from robot battery USB-UART Bridge (FT232R): VCCIO | Buck_3.3V | - | 3.3V | - | 15mA | 6 mil | - | - | - | - | - | - | - | - | - | - | - | - | - | - | -
IMU(LSM6DSR) VDD | - | Buck_3.3V | - | 3.3V | - | - | 6 mil | - | - | - | - | - | - | - | - | - | - | - | - | - | - | - | -
IMU(LSM6DSR) VDDIO | - | Buck_3.3V | - | 3.3V | - | - | 6 mil | - | - | - | - | - | - | - | - | - | - | - | - | - | - | - ESP32-Mini / ESP32-WROOM-32 | 8 mil ST-Link V3 | 6 mil

ontrolling through one of the PWM pin

12 A | Link

Link

Link

Link | Link
Link | Link

Link

Link

Link

Link | Link

Link

Link | Link
Link | Link

Link

Link | Link
Link Link | Link
Link | Link
Link | Link
Link | Link
Link | Link
Link | Link
Link | Link
Link | Link
Link | Link
Link | Link
Link | Link
Link | Link
Link | Link
Link | Link
Link | Link
Link | Link

Link

Link | Link
Link | Link
Link | Link Link | Link Link | Link
Link | Link Link

3000 mA

3000 mA

5.15 A

1.2 A

1.2 A

1.2A

1.2 A

0.8 A
0.8 A
0.8 A

0.8 A
0.8 A
0.8 A

0.3A

2.129 A

4 mA
(estimated)

700 mA

700 mA

700 mA
18 mA

7 mA

0.74A

45 mA

45 mA

45 mA

45 mA

45 mA

45 mA

1.8 mA

500 uA

5 uA

1.8 mA

1.8 mA

30mA
1.2 mA
1.2 mA
300 mA
2 mA

3.866 A

### 2.4 A

### 2.4 A

133 mil

133 mil

LFD-01m servo

LFD-01m servo

LFD-01m servo

1.598 A

0.543A OV2640 CAmera Module | Buck_3V3 | - | 3.3V | - | - | 130 mA | 6 mil | - | - | - | Link | Link | Link

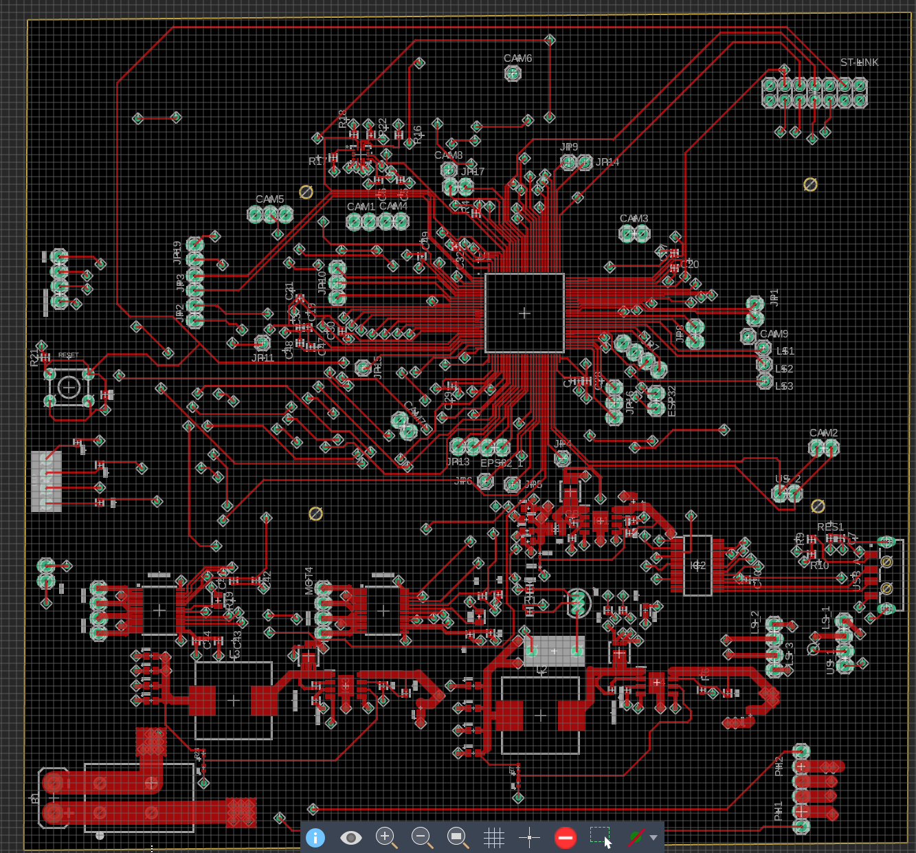
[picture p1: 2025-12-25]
layout/pcb_top.png

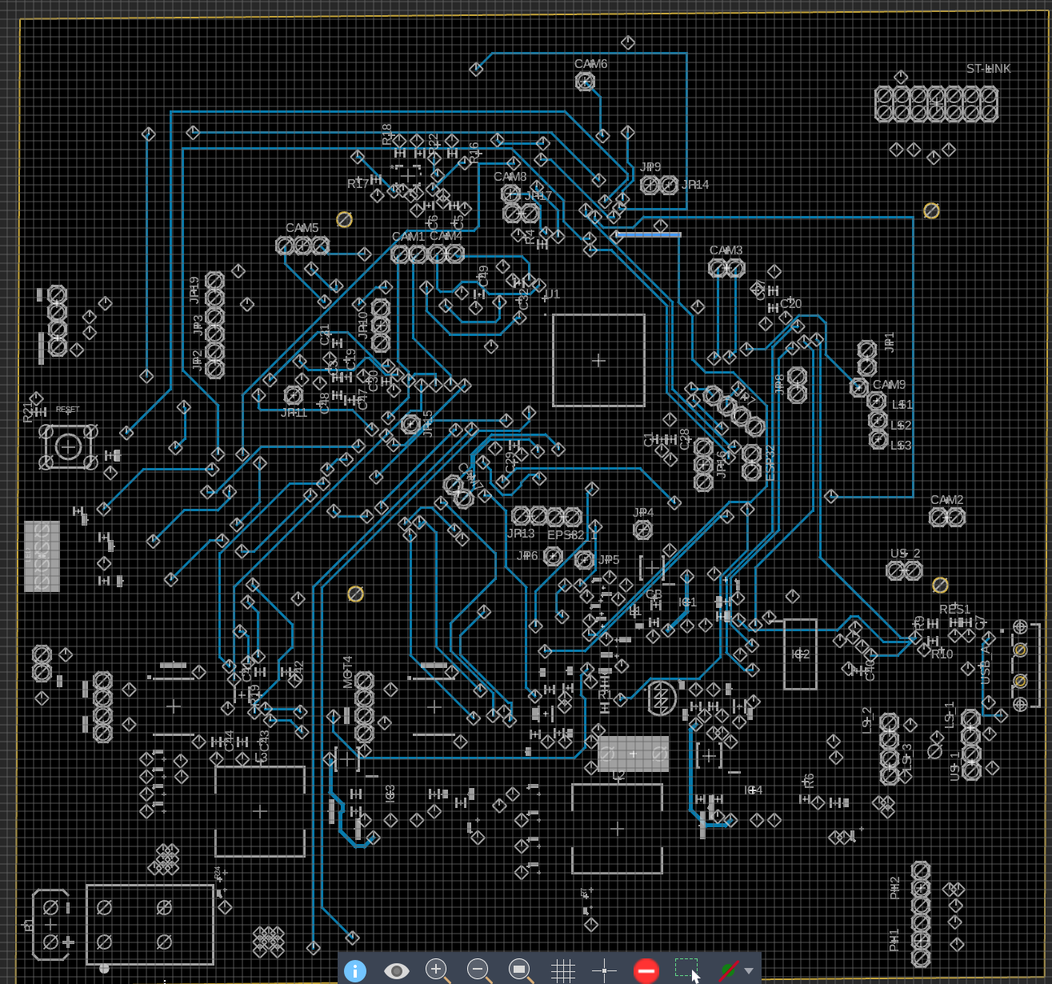
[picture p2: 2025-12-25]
layout/pcb_bottom.png

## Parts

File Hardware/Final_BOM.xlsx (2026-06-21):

Item | Reference Designators | Quantity | Manufacturer | Manufacturer Part # | Description/Value | Package | Mounting Type | Unit Cost | Total Cost | Datasheet | Website | Instruction/Notes
1 | JP7 | 1 | JST Sales America Inc. | B4B-XH-A | Connector Header 1X04 | Bulk | Through hole | $0.14 | $0.14 | Datasheet (https://www.jst-mfg.com/product/pdf/eng/eXH.pdf) | Link (https://www.digikey.com/en/products/detail/jst-sales-america-inc/B4B-XH-A/1651047) | Link (https://www.digikey.com/en/products/detail/3m/929400-01-04/681075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) | DNT
2 | C22,C24,C35 | 3 | Murata Electronics | GRM21BR61A226ME51L | 22 µF Capacitor | 0402 (1005 Metric) | Surface Mount | $0.19 | $0.57 | Datasheet (https://search.murata.co.jp/Ceramy/image/img/A01X/G101/ENG/GRM21BR61A226ME51-01.pdf) | Link (https://www.digikey.com/en/products/detail/murata-electronics/GRM21BR61A226ME51L/5027595)
3 | R11 | 1 | YAGEO | RC0402FR-07240RL | 240 Ohms Resistor | 0402 (1005 Metric) | Surface Mount | $0.10 | $0.10 | Datasheet (https://www.yageogroup.com/content/datasheet/asset/file/PYU-RC_GROUP_51_ROHS_L) | Link (https://www.digikey.com/en/products/detail/yageo/RC0402FR-07240RL/2827564?gclsrc=aw.ds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)
4 | C5 | 1 | Samsung Electro-Mechanics | CL10A475KP8NNNC | 4.7 µF Capacitor | 0402 (1005 Metric) | Surface Mount | $0.80 | $0.80 | Datasheet (https://mm.digikey.com/Volume0/opasdata/d220001/medias/docus/609/CL10A475KP8NNNC_Spec.pdf) | Link (https://www.digikey.com/en/products/detail/samsung-electro-mechanics/CL10A475KP8NNNC/3886702) | Link (https://www.digikey.com/en/products/detail/samsung-electro-mechanics/CL05A475MP5NRNC/3887140)
5 | CAM6, CAM8, CAM9, JP11, JP14, JP15, JP4, JP5, JP6, JP9, LS1, LS2, LS3 | 13 | JST Sales America Inc. | B1B-XH-AM | Connector Header 1X01 | Bulk | Through hole | $0.19 | $2.47 | Datasheet (https://www.jst-mfg.com/product/pdf/eng/eXH.pdf) | Link (https://www.digikey.com/en/products/detail/jst-sales-america-inc/B1B-XH-AM/1651025) | Link (https://www.digikey.com/en/products/detail/amphenol-cs-fci/861400011YO2LF/5201723)
6 | LED | 1 | Kingbright | WP154A4SEJ3VBDZGC/CA | Red, Green, Blue (RGB) 625nm Red, 525nm Green, 470nm Blue LED Indication - Discrete 2.2V Red, 3.3V Green, 3.3V Blue Radial - 4 Leads | 754-2153-ND | Through hole | $2.20 | $2.20 | Datasheet (https://www.kingbrightusa.com/images/catalog/SPEC/WP154A4SEJ3VBDZGC-CA.pdf) | Link (https://www.digikey.com/en/products/detail/kingbright/WP154A4SEJ3VBDZGC-CA/7597097) | Link (https://www.amazon.com/Tricolor-Multicolor-Lighting-Electronics-Components/dp/B01C19ENDM/)
7 | U1 | 1 | STMicroelectronics | STM32F429VIT6 | STM32F4 Microcontroller IC | 100-LQFP | Surface Mount | $14.28 | $14.28 | Datasheet (https://www.st.com/content/ccc/resource/technical/document/datasheet/03/b4/b2/36/4c/72/49/29/DM00071990.pdf/files/DM00071990.pdf/jcr:content/translations/en.D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) | Link (https://www.digikey.com/en/products/detail/stmicroelectronics/STM32F429VIT6/4357425)
8 | C10, C12, C19, C27, C28, C29, C30, C31, C32, C37, C40, C48, C49, C7 | 14 | TDK Corporation | C1005X7R1C104K050BC | 0.1 µF Capacitor | 0402 (1005 Metric) | Surface Mount | $0.10 | $1.40 | Datasheet (https://product.tdk.com/system/files/dam/doc/product/capacitor/ceramic/mlcc/catalog/mlcc_commercial_general_en.pdf) | Link (https://www.digikey.com/en/products/detail/tdk-corporation/C1005X7R1C104K050BC/2093220?gclsrc=aw.ds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)
9 | U2 | 1 | STMicroelectronics | LSM6DSRXTR | Accelerometer | 14-VFLGA Module | Surface Mount | $4.58 | $4.58 | Datasheet (https://www.st.com/resource/en/datasheet/lsm6dsrx.pdf) | Link (https://www.digikey.com/en/products/detail/stmicroelectronics/LSM6DSRXTR/10414337)
10 | CAM5, JP10, JP16, PH1, PH2 | 5 | JST Sales America Inc. | B3B-XH-A | Connector Header 1X03 | Bulk | Through hole | $0.11 | $0.55 | Datasheet (https://www.jst-mfg.com/product/pdf/eng/eXH.pdf) | Link (https://www.digikey.com/en/products/detail/jst-sales-america-inc/B3B-XH-A/1651046) | Link (https://www.digikey.com/en/products/detail/w%C3%BCrth-elektronik/61300311121/4846825)
12 | IC2 | 1 | Future Technology Devices International | FT232RL-REEL | UART USB Bridge 2.0 | 28-SSOP | Surface Mount | $4.95 | $4.95 | Datasheet (https://ftdichip.com/wp-content/uploads/2020/08/DS_FT232R.pdf) | Link (https://ftdichip.com/products/ft232rl/)
13 | Q1 | 1 | Diotec Semiconductor | 2N3904 | Bipolar (BJT) Transistor | TO-226-3, TO-92-3 (TO-226AA) Formed Leads | Through hole | $0.28 | $0.28 | Datasheet (https://diotec.com/request/datasheet/2n3904.pdf) | Link (https://www.digikey.com/en/products/detail/stmicroelectronics/2N3904/603420)
14 | C2, C4, C42, C44, C6 | 5 | TDK Corporation | C1005X7R1C104K050BC | 0.1 µF Capacitor | 0402 (1005 Metric) | Surface Mount | $0.10 | $0.50 | Datasheet (https://product.tdk.com/system/files/dam/doc/product/capacitor/ceramic/mlcc/catalog/mlcc_commercial_general_en.pdf) | Link (https://www.digikey.com/en/products/detail/tdk-corporation/C1005X7R1C104K050BC/2093220)
15 | C_BOOT, C_VCC, C_VCC1, CV, C3, C47 | 6 | Samsung Electro-Mechanics | CL05A105KP5NNNC | 1 µF Capacitor | 0402 (1005 Metric) | Surface Mount | $0.08 | $0.48 | Datasheet (https://mm.digikey.com/Volume0/opasdata/d220001/medias/docus/2384/CL05A105KP5NNN_Specsheet%20%281%29.pdf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..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) | Link (https://www.digikey.com/en/products/detail/samsung-electro-mechanics/CL05A105KP5NNNC/3886734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..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)
16 | USB_A | 1 | Molex | 480371000 | USB-A Connector 4 Position | Tray | Surface Mount, Right Angle; Through Hole | $1.43 | $1.43 | Datasheet (https://www.molex.com/content/dam/molex/molex-dot-com/products/automated/en-us/salesdrawingpdf/480/48037/480371000_sd.pdf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) | Link (https://www.digikey.com/en/products/detail/molex/0480371000/857604) | Link (https://www.digikey.com/en/products/detail/molex/0480371000/857604)
17 | L2, L3 | 2 | Würth Elektronik | 7443551280 | 2.8 µH Inductor | Nonstandard | Surface Mount | $3.48 | $6.96 | Datasheet (https://www.we-online.com/components/products/datasheet/7443551280.pdf) | Link (https://www.digikey.com/en/products/detail/w%C3%BCrth-elektronik/7443551280/1638531)
18 | J1 | 1 | Phoenix Contact | 1017503 | WireTerminal | Bulk | Through-hole (Wave soldering) | $1.06 | $1.06 | Datasheet (https://mm.digikey.com/Volume0/opasdata/d220001/medias/docus/896/1017503_Ds.pdf) | Link (https://www.digikey.com/en/products/detail/phoenix-contact/1017503/9346604)
19 | IC1, IC3, IC4 | 3 | Richtek USA Inc. | RT7258GSP | Buck Regulator | 8-soic (0.154", 3.90mm Width) | Surface Mount | $2.32 | $6.96 | Datasheet (https://drive.google.com/file/d/1BxTxwfJhr2AKTYy_Nv285g8NytwkJ0E0/view?usp=sharing) | Link (https://www.digikey.com/en/products/detail/richtek-usa-inc/RT7258GSP/3503828)
20 | R19, R20 | 2 | YAGEO | RC0603FR-0710KL | 10 kOhms Resistor | 0603 (1608 Metric) | Surface Mount | $0.10 | $0.20 | Datasheet (https://www.yageogroup.com/content/datasheet/asset/file/PYU-RC_GROUP_51_ROHS_L) | Link (https://www.digikey.com/en/products/detail/yageo/RC0603FR-0710KL/726880)
21 | R10 | 1 | YAGEO | RC0402FR-07100KL | 100 kOhms Resistor | 0402 (1005 Metric) | Surface Mount | $0.10 | $0.10 | Datasheet (https://www.yageogroup.com/content/datasheet/asset/file/PYU-RC_GROUP_51_ROHS_L) | Link (https://www.digikey.com/en/products/detail/yageo/RC0402FR-07100KL/726526?gclsrc=aw.ds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)
22 | R3, R5 | 2 | TE Connectivity Passive Product | CPF0402B18KE1 | 18 kOhms Resistor | 0402 (1005 Metric) | Surface Mount | $0.23 | $0.46 | Datasheet (https://www.te.com/commerce/DocumentDelivery/DDEController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) | Link (https://www.digikey.com/en/products/detail/te-connectivity-passive-product/CPF0402B18KE1/2381834)
23 | R13, R2, R23, R26, R4, R6, R8 | 7 | YAGEO | RC0402FR-07100KL | 100 kOhms Resistor | 0402 (1005 Metric) | Surface Mount | $0.10 | $0.70 | Datasheet (https://www.yageogroup.com/content/datasheet/asset/file/PYU-RC_GROUP_51_ROHS_L) | Link (https://www.digikey.com/en/products/detail/yageo/RC0402FR-07100KL/726526?gclsrc=aw.ds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)
24 | ST-LINK | 1 | Amphenol Positronic | DF07M30 | Connector Header 2X07 | Bulk | Surface Mount, Right Angle | $18.18 | $18.18 | Datasheet (https://mm.digikey.com/Volume0/opasdata/d220001/medias/docus/6155/C030revC_Autoshunt.pdf) | Link (https://www.digikey.com/en/products/detail/amphenol-positronic/DF07M30/18675597) | Link (https://www.digikey.com/en/products/detail/samtec-inc/TSW-107-07-F-D/6679083)
25 | R24, R7 | 2 | Panasonic Electronic Components | ERA-2AEB9312X | 93.1 kOhms Resistor | 0402 (1005 Metric) | Surface Mount | $0.10 | $0.20 | Datasheet (https://industrial.panasonic.com/cdbs/www-data/pdf/RDM0000/AOA0000C307.pdf) | Link (https://www.digikey.com/en/products/detail/panasonic-electronic-components/ERA-2AEB9312X/2026231)
26 | C_BOOT1, CB | 2 | Samsung Electro-Mechanics | CL05A105KP5NNNC | 1 µF Capacitor | 0402 (1005 Metric) | Surface Mount | $0.08 | $0.16 | Datasheet (https://mm.digikey.com/Volume0/opasdata/d220001/medias/docus/2384/CL05A105KP5NNN_Specsheet%20%281%29.pdf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..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) | Link (https://www.digikey.com/en/products/detail/samsung-electro-mechanics/CL05A105KP5NNNC/3886734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..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)
27 | R16, R17, R18, R22 | 4 | YAGEO | RC0402JR-074K7L | 4.7 kOhms Resistor | 0402 (1005 Metric) | Surface Mount | $0.10 | $0.40 | Datasheet (https://www.yageogroup.com/content/datasheet/asset/file/PYU-RC_GROUP_51_ROHS_L) | Link (https://www.digikey.com/en/products/detail/yageo/RC0402JR-074K7L/726477)
28 | U3, U5,U4 | 3 | Vishay Siliconix | SI7114DN-T1-E3 | N-Channel | PowerPAK,1212-8 | Surface Mount | $2.96 | $8.88 | Datasheet (https://www.vishay.com/docs/73039/si7114dn.pdf) | Link (https://www.digikey.com/en/products/detail/vishay-siliconix/SI7114DN-T1-E3/1656585)
29 | R14 | 1 | Panasonic Electronic Components | ERA-2AEB203X | 20 kOhms Resistor | 0402 (1005 Metric) | Surface Mount | $0.10 | $0.10 | Datasheet (https://industrial.panasonic.com/cdbs/www-data/pdf/RDM0000/AOA0000C307.pdf) | Link (https://www.digikey.com/en/products/detail/panasonic-electronic-components/ERA-2AEB203X/1706036)
30 | RES | 1 | YAGEO | RC0402FR-07100KL | 100 kOhms Resistor | 0402 (1005 Metric) | Surface Mount | $0.10 | $0.10 | Datasheet (https://www.yageogroup.com/content/datasheet/asset/file/PYU-RC_GROUP_51_ROHS_L) | Link (https://www.digikey.com/en/products/detail/yageo/RC0402FR-07100KL/726526)
31 | RESET | 1 | SCHURTER Inc. | 1301.9314.24 | Tactile Switch | - | Surface Mount | $0.47 | $0.47 | Datasheet (https://www.schurter.com/en/datasheet/typ_6x6_mm_tact_switches.pdf) | Link (https://www.digikey.com/en/products/detail/schurter-inc/1301-9314-24/8536716) | Link (https://www.digikey.com/en/products/detail/c-k/PTS645SH43-2-LFS/3861368)
32 | R12, R15 | 2 | TE Connectivity Passive Product | 352239RFT | 39 Ohms Resistor | 2512 (6332 Metric) | Surface Mount | $1.05 | $2.10 | Datasheet (https://www.te.com/commerce/DocumentDelivery/DDEController?Action=srchrtrv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) | Link (https://www.digikey.com/en/products/detail/te-connectivity-passive-product/352239RFT/5245088) | Link (https://www.digikey.com/en/products/detail/vishay-dale/RCS040239R0FKED/5867540)
33 | L1 | 1 | Murata Electronics | DFE322512F-4R7M=P2 | 4.7 µH Inductor | 1210 (3225 Metric) | Surface Mount | $0.44 | $0.44 | Datasheet (https://search.murata.co.jp/Ceramy/image/img/P02/J(E)TE243A-0019.pdf) | Link (https://www.digikey.com/en/products/detail/murata-electronics/DFE322512F-4R7M-P2/9815916)
34 | R1 | 1 | YAGEO | RC0603FR-0710KL | 10 kOhms Resistor | 0603 (1608 Metric) | Surface Mount | $0.10 | $0.10 | Datasheet (https://www.yageogroup.com/content/datasheet/asset/file/PYU-RC_GROUP_51_ROHS_L) | Link (https://www.digikey.com/en/products/detail/yageo/RC0603FR-0710KL/726880)
35 | C11, C13, C14, C16, C18, C21, C23, C25, C26, C33, C34 | 11 | Samsung Electro-Mechanics | CL21A226MPQNNNE | 22 Capacitor | 0805 (2012 Metric) | Surface Mount | $0.15 | $1.65 | Datasheet (https://mm.digikey.com/Volume0/opasdata/d220001/medias/docus/6697/CL21A226MPQNNN.pdf) | Link (https://www.digikey.com/en/products/detail/samsung-electro-mechanics/CL21A226MPQNNNE/3888568) | Link (https://www.mouser.com/ProductDetail/YAGEO/CC0603MRX5R6BB226?qs=IvkZ4pJZlB3K%252BVkAL36Ang%3D%3D)
36 | CAM, CAM1, CAM2, CAM3, CAM4, CAM7, EPS32_1, ESP32, ESP32_PW, FAN, JP1, JP13, JP17, JP19, JP2, JP3, JP8, LS_1, LS_2, LS_3, MOT1, MOT2, MOT3, MOT4, US_1, US_2 | 26 | JST Sales America Inc. | S2B-PH-K-S | Connector Header 1X02 | Bulk | Through hole | $0.10 | $2.60 | Datasheet (https://www.jst-mfg.com/product/pdf/eng/eXH.pdf) | Link (https://www.digikey.com/en/products/detail/jst-sales-america-inc/B2B-XH-A/1651045?gclsrc=aw.ds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) | Link (https://www.digikey.com/en/products/detail/mill-max-manufacturing-corp/800-10-002-20-001000/7762570)
37 | C16, C18, C21, C23, C25, C26, C33, C34 | 8 | Samsung Electro-Mechanics | CL10A226MP8NUNE | 22 µF Capacitor | 0402 (1005 Metric) | Surface Mount | $0.08 | $0.64 | Datasheet (https://mm.digikey.com/Volume0/opasdata/d220001/medias/docus/2901/CL10A226MP8NUNC_Spec.pdf) | Link (https://www.digikey.com/en/products/detail/samsung-electro-mechanics/CL10A226MP8NUNE/3886932?gclsrc=aw.ds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)
38 | R9 | 1 | YAGEO | RC0402JR-074K7L | 4.7 kOhms Resistor | 0402 (1005 Metric) | Surface Mount | $0.10 | $0.10 | Datasheet (https://www.yageogroup.com/content/datasheet/asset/file/PYU-RC_GROUP_51_ROHS_L) | Link (https://www.digikey.com/en/products/detail/yageo/RC0402JR-074K7L/726477?gclsrc=aw.ds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)
39 | C1, C20 | 2 | Samsung Electro-Mechanics | CL05A225MQ5NNNC | 2.2 µF Capacitor | 0805 (2012 Metric) | Surface Mount | $0.08 | $0.16 | Datasheet (https://mm.digikey.com/Volume0/opasdata/d220001/medias/docus/2614/CL05A225MQ5NNNC_Spec.pdf) | LInk (https://www.digikey.com/en/products/detail/samsung-electro-mechanics/CL05A225MQ5NNNC/3887127)
40 | MOT_IC1, MOT_IC2 | 2 | Toshiba Semiconductor and Storage | TB6612FNG,C,8,EL | IC Motor Driver | 24-LSSOP (0.220", 5.60mm Width) | Surface Mount | $1.82 | $3.64 | Datasheet (https://toshiba.semicon-storage.com/info/TB6612FNG_datasheet_en_20141001.pdf?did=10660&prodName=TB6612FNG) | Link (https://www.digikey.com/en/products/detail/toshiba-semiconductor-and-storage/TB6612FNG-C-8-EL/1730070)
41 | C15 | 1 | Murata Electronics | GRM21BR71A106KA73L | 10 Capacitor | 0805 (2012 Metric) | Surface Mount | $0.12 | $0.12 | Datasheet (https://search.murata.co.jp/Ceramy/image/img/A01X/G101/ENG/GRM21BR71A106KA73-01.pdf) | Link (https://www.digikey.com/en/products/detail/murata-electronics/GRM21BR71A106KA73L/5027600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..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) | Link (https://www.mouser.com/ProductDetail/TAIYO-YUDEN/MBASL168BB5106MTNA01?qs=tlsG%2FOw5FFiWnia%252B9QDAZA%3D%3D)
42 | C17 | 1 | Samsung Electro-Mechanics | CL10A475KP8NNNC | 4.7 µFCapacitor | 0402 (1005 Metric) | Surface Mount | $0.08 | $0.08 | Datasheet (https://mm.digikey.com/Volume0/opasdata/d220001/medias/docus/609/CL10A475KP8NNNC_Spec.pdf) | Link (https://www.digikey.com/en/products/detail/samsung-electro-mechanics/CL10A475KP8NNNC/3886702)
43 | R21 | 1 | YAGEO | RC0603FR-0710KL | 11 kOhms Resistor | 0603 (1608 Metric) | Surface Mount | $0.10 | $0.10 | Datasheet (https://www.yageogroup.com/content/datasheet/asset/file/PYU-RC_GROUP_51_ROHS_L) | Link (https://www.digikey.com/en/products/detail/yageo/RC0603FR-0710KL/726880) | Link (https://www.digikey.com/en/products/detail/yageo/RC0603FR-0711KL/726897)
44 | C41, C43, C8, C9 | 4 | Samsung Electro-Mechanics | CL05A106MP5NUNC | 10 µF Capacitor | 0402 (1005 Metric) | Surface Mount | $0.80 | $3.20 | Datasheet (https://mm.digikey.com/Volume0/opasdata/d220001/medias/docus/2614/CL05A106MP5NUNC_Spec.pdf) | Link (https://www.digikey.com/en/products/detail/samsung-electro-mechanics/CL05A106MP5NUNC/3887108)
45 | RES1 | 1 | YAGEO | RC0402FR-071ML | 1mOhm Resistor | 0402 (1005 Metric) | Surface Mount | $0.10 | $0.10 | Datasheet (https://www.yageogroup.com/content/datasheet/asset/file/PYU-RC_GROUP_51_ROHS_L) | Link (https://www.digikey.com/en/products/detail/yageo/RC0402FR-071ML/726515) | Link (https://www.digikey.com/en/products/detail/yageo/RC0402FR-071ML/726515?gclsrc=aw.ds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)
46 | R25 | 1 | Panasonic Electronic Components | ERJ-2RKF6202X | 62 kOhms | 0402 (1005 Metric) | Surface Mount | $0.10 | $0.10 | Datasheet (https://industrial.panasonic.com/cdbs/www-data/pdf/RDA0000/AOA0000C304.pdf) | Link (https://www.digikey.com/en/products/detail/panasonic-electronic-components/ERJ-2RKF6202X/1746262)
 |  |  |  |  |  |  | Total | $64.23 | $94.79

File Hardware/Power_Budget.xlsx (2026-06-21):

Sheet: Power Budget
 |  |  |  |  | Electrical Inputs |  |  |  | Temperature |  |  |  |  |  | Power + Efficiency |  |  |  | Noise / Ripple Design |  |  |  | Passive Components |  |  | Protection / Documentation
Component | Pins | Function / Role | Source Rail | Output Rail | V_in (V) | V_out (V) | I_typ (mA) | I_peak in (mA) | trace_in | trace_in | I_peak out (mA) |  | trace_out | Duty (%) | P_out (mW) | η (%) | P_in (mW) | P_loss (mW) | Noise Sensitivity | Allowed Ripple/Noise (mVpp) | Est. Ripple (mVpp) | Post-Filter Type | Local Capacitance (F) | Resistors (Ω) | Inductance (H) | Protection | Notes | Datasheet | Design | Distributor
Zeee 2S Lipo Battery 2200mAh 7.4V 50C Shorty Pack Battery with XT60 Connector |  | Main power source | BAT_7.4V | - | - | 7.4 V | - |  |  |  | 12 A | 150 mil | 948 mil | - | - | - | - | - | - | - | - | - | - | - | - | - | Two 3.7 V 1800 mAh Li-ion cells in series. Typical 1C continuous discharge, 2C peak. | Link (https://www.amazon.com/Zeee-Connector-Helicopter-Airplane-Quadcopter/dp/B0BYNKBKGT) | you need connector on your board | Hiwonder
LFD-218 servo | Signal Wire Positive pole of power supply Ground Wire | High-torque PWM digital servo for arm joints | BAT_7.4V | - | 7.4V | - | 100 mA | 3000 mA | 75 mil | 181 mil | - |  | - | - | - | - | - | - |  |  |  |  |  |  |  |  | Full-metal digital servo for arm joints. No-load 100 mA. Locked-rotor (stall) 2.4–3 A. Works from 2S Li-ion/LiPo rail. PWM signal from MCU, high current drawn from battery rail. | Link (https://www.hiwonder.com/products/ldx-218) |  | Hiwonder
LD-1501MG servo | White WireSignal input Red WireConnect to 7.4 V Black WireConnect to ground | High-precision PWM digital servo (used for base / shoulder / elbow joints) | BAT_7.4V | - | 7.4V | - | 100 mA | 3000 mA | 75 mil | 181 mil | - |  | - | - | - | - | - | - |  |  |  |  |  |  |  |  | Metal-gear servo. Working voltage 6–8.4 V. No-load 100 mA. Stall 2.4–3 A. PWM control. Used for precise joints. | Link (https://www.hiwonder.com/products/masterpi?variant=39783006961751) |  | Hiwonder
Buck 5V(RT7258) |  | Step-down buck: BAT_7.4V → Buck_5V rail for 5 V loads | BAT_7.4V | Buck_5V | BAT_7.4V | 5 V | - | 3.866 A | 60 mil | 256 mil | 5.15 A | 60 mil | 380 mil | - | 25.75 W | 90 % | 28.611 W | 2.861W |  |  |  |  |  |  |  |  |  | Link (https://drive.google.com/file/d/1BxTxwfJhr2AKTYy_Nv285g8NytwkJ0E0/view?usp=sharing) | Link (https://docs.google.com/document/d/1QCWfKd3IMi0ioL2D__X-LOeG5Ttm0fEpJ_ohpv5i1r4/edit?usp=sharing)
TT Motor 1 | 1 pin for power another to ground | Drive motor (Mecanum wheel) | Buck_5V | - | 5V | - | 100 mA (assumpton) | 1.2 A | - | 51 mil | - |  | - | - | - | - | - | - |  |  |  |  |  |  |  |  | Ratio 1:42, Weight 30 g, Speed 150 RPM, Size 63×22×19 mm, Works with TurboPi/MasterPi/GoGoPi/4WD | Link (https://www.hiwonder.com/products/high-quality-tt-motor?variant=40452469686359) | Link (https://www.hiwonder.com/products/tt-motor-plastic?variant=40452432265303&_pos=1&_sid=790ce7e0f&_ss=r)
TT Motor 2 |  | Drive motor (Mecanum wheel) | Buck_5V | - | 5V | - | - | 1.2 A | - | 51 mil | - |  | - | - | - | - | - | - |  |  |  |  |  |  |  |  | Ratio 1:42, Weight 30 g, Speed 150 RPM, Size 63×22×19 mm, Works with TurboPi/MasterPi/GoGoPi/4WD | Link (https://www.hiwonder.com/products/high-quality-tt-motor?variant=40452469686359)
TT Motor 3 |  | Drive motor (Mecanum wheel) | Buck_5V | - | 5V | - | - | 1.2A | - | 51 mil | - |  | - | - | - | - | - | - |  |  |  |  |  |  |  |  | Ratio 1:42, Weight 30 g, Speed 150 RPM, Size 63×22×19 mm, Works with TurboPi/MasterPi/GoGoPi/4WD | Link (https://www.hiwonder.com/products/high-quality-tt-motor?variant=40452469686359)
TT Motor 4 |  | Drive motor (Mecanum wheel) | Buck_5V | - | 5V | - | - | 1.2 A | - | 51 mil | - |  | - | - | - | - | - | - |  |  |  |  |  |  |  |  | Ratio 1:42, Weight 30 g, Speed 150 RPM, Size 63×22×19 mm, Works with TurboPi/MasterPi/GoGoPi/4WD | Link (https://www.hiwonder.com/products/high-quality-tt-motor?variant=40452469686359)
Motor Driver ICs 1 VM (TB6612FNG) |  | Input to Motor | Buck_5V |  |  |  |  | 2.4 A |  | 133 mil | - |  | - | - | - | - | - | -
Motor Driver ICs 1 VM1 TB6612FNG |  |  | - | - | 5V | - | - | 0.8 A | 23 mil | 30 mil | - |  | - | - | - | - | - | - |  |  |  |  |  |  |  |  | You feed VM = 12 V from your battery through the power distribution tree to actually spin the DC motors. | Link (https://drive.google.com/file/d/10XPrb-pou5ZK269VqcwyoNUZbCF5IOtA/view) | Link (https://docs.google.com/document/d/1oVUuJoe4aIcGW8yYIsCojVU68kr35iCsHVQU-okVEos/edit?usp=sharing)
Motor Driver ICs 1 VM2 TB6612FNG |  |  | - |  |  |  |  | 0.8 A | 23 mil | 30 mil | - |  | - | - | - | - | - | -
Motor Driver ICs 1 VM3 TB6612FNG |  |  | - |  |  |  |  | 0.8 A | 23 mil | 30 mil | - |  | - | - | - | - | - | -
Motor Driver ICs 2 VM TB6612FNG |  |  | Buck_5V |  |  |  |  | 2.4 A |  | 133 mil | - |  | - | - | - | - | - | -
Motor Driver ICs 2 VM1 |  |  | - |  |  |  |  | 0.8 A | 23 mil | 30 mil | - |  | - | - | - | - | - | -
Motor Driver ICs 2 VM2 |  |  | - |  |  |  |  | 0.8 A | 23mil | 30 mil | - |  | - | - | - | - | - | -
Motor Driver ICs 2 VM3 |  |  | - |  |  |  |  | 0.8 A | 23 mil | 30 mil | - |  | - | - | - | - | - | -
Motor Driver ICs 1 Channel A |  | Output to Motor 1 | - | - | - | - | - | - |  | - | 1.2 A | 22 mil | 51 mil | - | - | - | - | -
Motor Driver ICs 1 Channel B |  | Output to Motor 2 | - | - | - | - | - | - |  | - | 1.2 A | 22 mil | 51 mil | - | - | - | - | -
Motor Driver ICs 2 Channel A |  | Output to Motor 3 | - | - | - | - | - | - |  | - | 1.2 A | 22 mil | 51 mil | - | - | - | - | -
Motor Driver ICs 2 Channel B |  | Output to Motor 4 | - | - | - | - | - | - |  | - | 1.2 A | 22 mil | 51 mil | - | - | - | - | -
Cooling Fan Service | 1 pin for power another to ground |  | Buck_5V | - | 5V | - | - | 0.3A | - | 10 mil | - | - | - | - | - | - | - | - |  |  |  |  |  |  |  |  |  |  | Link (https://www.youtube.com/watch?v=9WS93o6j0RU)
Buck 5V(RT7258)_2 |  | Step-down buck: BAT_7.4V → Buck_5V rail for 5 V loads | BAT_7.4V | Buck_5V | BAT_7.4V | 5 V | - | 1.598 A | 41 mil | 78 mil | 2.129 A | 56 mil | 88 mil | - | 11.828 W | 90 % | 10.645W | 1.183 W |  |  |  |  |  |  |  |  |  | Link (https://drive.google.com/file/d/1BxTxwfJhr2AKTYy_Nv285g8NytwkJ0E0/view?usp=sharing) | Link (https://docs.google.com/document/d/1QCWfKd3IMi0ioL2D__X-LOeG5Ttm0fEpJ_ohpv5i1r4/edit?usp=sharing)
Ultrasonic Distance Sensor | Pin Description 5V Power input GND Ground cable SDA SDA data cable SCL SCL clock cable | I²C ultrasonic distance sensor with RGB indicator for obstacle detection | Buck_5V | - | 5V | - | 2 mA | 4 mA (estimated) |  | 6 mil | - |  | - | - |  |  |  |  |  |  |  |  |  |  |  |  |  | Link (https://www.hiwonder.com/products/glowy-rgb-ultrasonic-sensor?_pos=6&_sid=adc380eec&_ss=r) | Link (https://docs.google.com/document/d/1oxFB7l_kMhTM32chsMz2aNlia8NCxBjFPgBF54qPqMA/edit?usp=sharing)
LFD-01m servo | Red Wire: Positive pole of power supply (VCC) Brown/Black Wire: Ground wire (GND) Orange/Yellow Wire: Signal wire (PWM input) | - | Buck_5V | - | 5V | - | 50 mA | 700 mA |  | 25 mil | - |  | - | - |  |  |  |  |  |  |  |  |  |  |  |  | Rotate speed 0.12 s/60° @ 4.8 V, 0.10 s/60° @ 6 V; Locked torque 1.5 kg·cm @ 4.8 V / 1.8 kg·cm @ 6 V; Weight 14 g; PWM pulse 500–2500 µs (0–180°) | Link (https://manuals.plus/asin/B081T2G4PN) |  | Hiwonder
LFD-01m servo |  | Small digital servo for robotic joints; PWM-controlled; draws 50 mA typical, up to 700 mA when stalled. | Buck_5V | - | 5V | - | 50 mA | 700 mA |  | 25 mil | - |  | - | - |  |  |  |  |  |  |  |  |  |  |  |  | Rotate speed 0.12 s/60° @ 4.8 V, 0.10 s/60° @ 6 V; Locked torque 1.5 kg·cm @ 4.8 V / 1.8 kg·cm @ 6 V; Weight 14 g; PWM pulse 500–2500 µs (0–180°) | Link (https://manuals.plus/asin/B081T2G4PN) | Link (https://www.hiwonder.com/products/masterpi?variant=39783006961751) | Hiwonder
LFD-01m servo |  | - | Buck_5V | - | 5V | - | 50 mA | 700 mA |  | 25 mil | - |  | - | - |  |  |  |  |  |  |  |  |  |  |  |  | Rotate speed 0.12 s/60° @ 4.8 V, 0.10 s/60° @ 6 V; Locked torque 1.5 kg·cm @ 4.8 V / 1.8 kg·cm @ 6 V; Weight 14 g; PWM pulse 500–2500 µs (0–180°) | Link (https://manuals.plus/asin/B081T2G4PN) |  | Hiwonder
USB-UART Bridge (FT232R): VCC |  |  | Buck_5V | - | 5V | - | 15 mA | 18 mA |  | 6 mil | - |  | - | - | - | - | - | - | - | - | - | - | - | - | - | - |  | Link (https://drive.google.com/file/d/1CjxIGrBiV04YFt3wU46lktcpQObRsXG4/view) | Link (https://docs.google.com/document/d/1xZ_au0ro0PvCiY00usshoseaw_nDDmyE88dPRQ2b89U/edit?usp=sharing)
Buzzers | Driven by PB8 through NPN transistor | Audio alert device for robot status/warnings (startup beeps, error alerts). | Buck5V2 | - | Buck5V_2 | - | - | 7 mA |  | 6mil |  |  |  | - |  |  |  |  |  |  |  |  |  |  |  |  |  | Link (https://a.co/d/jcGmakb) | Link (https://docs.google.com/document/d/10u8wQ8U-oJS3RkHav_5R2t8Pnj9GEn-M3JeaACq_S8g/edit?usp=sharing)
Buck 3V3(RT7258) |  |  | Buck 5V(RT7258)_2 | Buck_3.3V | 5V | 3.3 V |  | 0.543A |  | 18 mil | 0.74A | 21 mil | 27 mil |  | 2.443W | 90% | 2.174W | 0.271W |  |  |  |  |  |  |  |  |  | Link (https://drive.google.com/file/d/1Dk_rlcV0uIM5bMX1gGNoYWSgdpOTTRi7/view?usp=drive_link) | Link (https://docs.google.com/document/d/1J6YAh5-rjMbYfP9mwBF0tXQxmCSiALvsUJuWbPmBxAY/edit?usp=sharing)
OV2640 Camera Module |  |  | Buck_3V3 | - | 3.3V | - | - | 130 mA |  | 6 mil | - |  | - | - |  |  |  |  |  |  |  |  |  |  |  |  |  | Link (https://www.datasheetbank.com/pdf-view/OV2640-OMNIVISION-V2?utm_source=chatgpt.com) | Link (https://a.co/d/jfZv8tX) | Link (https://docs.google.com/document/d/1fy8zBMQDv8P3qzZUk-_U87qECEPaSzipeKCsA85KBwY/edit?usp=sharing)
MCU (STM32F427xx) |  | Main system microcontroller that runs the robot’s control logic, sensor processing, communication interfaces, and actuator commands. | Buck_3.3V | - | 3.3 V | - | - | - |  | - | - |  | - | - |  | - |  |  |  |  |  |  |  |  |  |  |  | Link (https://drive.google.com/file/d/1hRkt1TDSUxktWNqDx1tddKAdOWSRiARy/view?usp=drive_link) | Link (https://docs.google.com/document/d/1mb4skiESd2W2v5ZP3vbB_So8kpMBS8JisSbLIfouDZs/edit?usp=sharing)
MCU:VDD |  | Main 3.3 V digital power for MCU core and I/O (total of all VDD pins) | - | - | - | - | - | 270 mA |  | 7 mil | - |  | - | - |  | - |  |  |  |  |  |  |  |  |  |  |  | Link (https://drive.google.com/file/d/1hRkt1TDSUxktWNqDx1tddKAdOWSRiARy/view?usp=drive_link) | Link (https://docs.google.com/document/d/1mb4skiESd2W2v5ZP3vbB_So8kpMBS8JisSbLIfouDZs/edit?usp=sharing)
MCU:VDD1 |  | - | - | - | - | - | - | 45 mA |  | 6 mil | - |  | - | - |  | - |  |  |  |  |  |  | VDD1 C_7 = 100 nF |  |  |  |  | Link (https://drive.google.com/file/d/1hRkt1TDSUxktWNqDx1tddKAdOWSRiARy/view?usp=drive_link) | Link (https://docs.google.com/document/d/1mb4skiESd2W2v5ZP3vbB_So8kpMBS8JisSbLIfouDZs/edit?usp=sharing)
MCU:VDD2 |  | - | - | - | - | - | - | 45 mA |  | 6 mil | - |  | - | - |  | - |  |  |  |  |  |  | VDD2 C_8 = 100 nF |  |  |  |  | Link (https://drive.google.com/file/d/1hRkt1TDSUxktWNqDx1tddKAdOWSRiARy/view?usp=drive_link) | Link (https://docs.google.com/document/d/1mb4skiESd2W2v5ZP3vbB_So8kpMBS8JisSbLIfouDZs/edit?usp=sharing)
MCU:VDD3 |  | - | - | - | - | - | - | 45 mA |  | 6 mil | - |  | - | - |  | - |  |  |  |  |  |  | VDD3 C_9 = 100 nF |  |  |  |  | Link (https://drive.google.com/file/d/1hRkt1TDSUxktWNqDx1tddKAdOWSRiARy/view?usp=drive_link) | Link (https://docs.google.com/document/d/1mb4skiESd2W2v5ZP3vbB_So8kpMBS8JisSbLIfouDZs/edit?usp=sharing)
MCU:VDD4 |  | - | - | - | - | - | - | 45 mA |  | 6 mil | - |  | - | - |  | - |  |  |  |  |  |  | VDD4 C_10 = 100 nF |  |  |  |  | Link (https://drive.google.com/file/d/1hRkt1TDSUxktWNqDx1tddKAdOWSRiARy/view?usp=drive_link) | Link (https://docs.google.com/document/d/1mb4skiESd2W2v5ZP3vbB_So8kpMBS8JisSbLIfouDZs/edit?usp=sharing)
MCU:VDD5 |  | - | - | - | - | - | - | 45 mA |  | 6 mil | - |  | - | - |  | - |  |  |  |  |  |  | VDD5 C_11 = 100 nF |  |  |  |  | Link (https://drive.google.com/file/d/1hRkt1TDSUxktWNqDx1tddKAdOWSRiARy/view?usp=drive_link) | Link (https://docs.google.com/document/d/1mb4skiESd2W2v5ZP3vbB_So8kpMBS8JisSbLIfouDZs/edit?usp=sharing)
MCU:VDD6 |  | - | - | - | - | - | - | 45 mA |  | 6 mil | - |  | - | - |  | - |  |  |  |  |  |  | VDD6 C_12 = 100 nF |  |  |  |  | Link (https://drive.google.com/file/d/1hRkt1TDSUxktWNqDx1tddKAdOWSRiARy/view?usp=drive_link) | Link (https://docs.google.com/document/d/1mb4skiESd2W2v5ZP3vbB_So8kpMBS8JisSbLIfouDZs/edit?usp=sharing)
MCU:VDDA |  | - | - | - | - | - | 1.6 mA | 1.8 mA |  | 6 mil | - |  | - | - |  | - |  |  |  |  |  |  | VDDA C_13 = 100 nF |  |  |  |  | Link (https://drive.google.com/file/d/1hRkt1TDSUxktWNqDx1tddKAdOWSRiARy/view?usp=drive_link) | Link (https://docs.google.com/document/d/1mb4skiESd2W2v5ZP3vbB_So8kpMBS8JisSbLIfouDZs/edit?usp=sharing)
MCU:VREF+ |  | Analog reference input that sets full-scale range for the ADC | - | - | - | - | 300 uA | 500 uA |  | 6 mil | - |  | - | - |  | - |  |  |  |  |  |  | VREF+ C_14 = 100 nF + C_15 = 1 uF |  |  |  |  | Link (https://drive.google.com/file/d/1hRkt1TDSUxktWNqDx1tddKAdOWSRiARy/view?usp=drive_link) | Link (https://docs.google.com/document/d/1mb4skiESd2W2v5ZP3vbB_So8kpMBS8JisSbLIfouDZs/edit?usp=sharing)
MCU:VBAT |  | Backup supply for RTC and backup registers when main 3.3 V is off | - | - | - | - | 1 uA | 5 uA |  | 6 mil | - |  | - | - |  | - |  |  |  |  |  |  | - |  |  |  |  | Link (https://drive.google.com/file/d/1hRkt1TDSUxktWNqDx1tddKAdOWSRiARy/view?usp=drive_link) | Link (https://docs.google.com/document/d/1mb4skiESd2W2v5ZP3vbB_So8kpMBS8JisSbLIfouDZs/edit?usp=sharing)
MCU:VCAP1 |  | Internal 1.2 V core regulator output – decoupling cap only | - | - | - | - | - | - |  | - | - |  | - | - |  | - |  |  |  |  |  |  | VCAP1 C_16 = 2.2 uF |  |  |  |  | Link (https://drive.google.com/file/d/1hRkt1TDSUxktWNqDx1tddKAdOWSRiARy/view?usp=drive_link) | Link (https://docs.google.com/document/d/1mb4skiESd2W2v5ZP3vbB_So8kpMBS8JisSbLIfouDZs/edit?usp=sharing)
MCU:VCAP2 |  | Internal 1.2 V core regulator output – decoupling cap only | - | - | - | - | - | - |  | - | - |  |  | - |  | - |  |  |  |  |  |  | VCAP2 C_17 = 2.2 uF |  |  |  |  | Link (https://drive.google.com/file/d/1hRkt1TDSUxktWNqDx1tddKAdOWSRiARy/view?usp=drive_link) | Link (https://docs.google.com/document/d/1mb4skiESd2W2v5ZP3vbB_So8kpMBS8JisSbLIfouDZs/edit?usp=sharing)
GPIO_PIN | - | - | - | - | - | - | 8mA | - |  | - | 20 mA
CHANZON Led (G/B) | Controlling through one of the PWM pin |  | PA5/PB0 | - | MCU_3.3V | 3.1 V | - | 20 mA |  |  |  |  |  |  |  |  |  |  |  |  |  |  |  |  |  |  |  | Link (https://www.amazon.com/dp/B01C19ENDM)
CHANZON Led (R) | ? |  | PA3 | - | MCU_3.3V | 2.1 V | - | 20 mA |  |  |  |  |  |  |  |  |  |  |  |  |  |  |  |  |  |  |  | Link
Motor Driver ICs 1 VCC |  | Logic supply for input signal detection, internal H-bridge control, standby logic | Buck_3.3V | - | 3.3 V | - | 1.1 mA | 1.8 mA |  | 6 mil | - |  | - | - | - | - | - | - | - | - | - | - | VCC C_5=10uF C_6= 0.1uF | - | - | - | You feed VCC = 3.3 V from the STM32F429 logic rail (so PWM, DIR, and STBY pins all see 3.3 V logic levels). | Link (https://drive.google.com/file/d/10XPrb-pou5ZK269VqcwyoNUZbCF5IOtA/view?usp=drive_link) | Link (https://docs.google.com/document/d/1oVUuJoe4aIcGW8yYIsCojVU68kr35iCsHVQU-okVEos/edit?usp=sharing)
Motor Driver ICs 2 VCC |  |  | Buck_3.3V | - | 3.3 V | - | 1.1 mA | 1.8 mA |  | 6 mil | - |  | - | - | - | - | - | - | - | - | - | - | VCC C_5=10uF C_6= 0.1uF | - | - | - | You feed VCC = 3.3 V from the STM32F429 logic rail (so PWM, DIR, and STBY pins all see 3.3 V logic levels). | Link (https://drive.google.com/file/d/10XPrb-pou5ZK269VqcwyoNUZbCF5IOtA/view?usp=drive_link) | Link (https://docs.google.com/document/d/1oVUuJoe4aIcGW8yYIsCojVU68kr35iCsHVQU-okVEos/edit?usp=sharing)
USB-UART Bridge (FT232R) |  | USB-to-UART interface for programming / debug | - | - | - | - | - | - |  |  | - |  | - | - | - | - | - | - | - | - | - | - | VCC C_1=100nF C_2=100nF C_3=4.7uF 3V3 out C_4 = 100 nF | Pin 1 USB R_1 =4k7 R_2 =10k | - | - | USB powered only. Not from robot battery | Link (https://drive.google.com/file/d/1CjxIGrBiV04YFt3wU46lktcpQObRsXG4/view) | Link (https://docs.google.com/document/d/1xZ_au0ro0PvCiY00usshoseaw_nDDmyE88dPRQ2b89U/edit?usp=sharing)
USB-UART Bridge (FT232R): VCCIO |  |  | Buck_3.3V | - | 3.3V | - | 15mA | 30mA |  | 6 mil | - |  |  | - | - | - | - | - | - | - | - | - | - | - | - | - | - | Link (https://drive.google.com/file/d/1CjxIGrBiV04YFt3wU46lktcpQObRsXG4/view) | Link (https://docs.google.com/document/d/1xZ_au0ro0PvCiY00usshoseaw_nDDmyE88dPRQ2b89U/edit?usp=sharing)
IMU(LSM6DSR) VDD |  | - | Buck_3.3V | - | 3.3V | - | - | 1.2 mA |  | 6 mil | - |  | - | - | - | - | - | - | - | - | - | - | - | - | - | - | - | Link (https://drive.google.com/file/d/1sJYi0Ztong-i2RurtcVjR6GrNYR1oAbC/view?usp=sharing) | Link (https://docs.google.com/document/d/1xCbx-SNTvTGnT3GMFbaMSSJm2I0n1Ul8ZeeuAHlAf-4/edit?usp=sharing)
IMU(LSM6DSR) VDDIO |  | - | Buck_3.3V | - | 3.3V | - | - | 1.2 mA |  | 6 mil | - |  | - | - | - | - | - | - | - | - | - | - | - | - | - | -
ESP32-Mini / ESP32-WROOM-32 |  |  |  |  |  |  |  | 300 mA |  | 8 mil |  |  |  |  |  |  |  |  |  |  |  |  |  |  |  |  |  | Link (https://drive.google.com/file/d/1vVNAsPO0WSp-ao_Qmh--nb88oStUAPe6/view?usp=sharing) | Link (https://docs.google.com/document/d/1JLg8v0JtL__4046kSek7rasGeKHsfShjYDlv42wvQsg/edit?usp=sharing)
ST-Link V3 |  |  |  |  |  |  |  | 2 mA |  | 6 mil |  |  |  |  |  |  |  |  |  |  |  |  |  |  |  |  |  | Link (https://drive.google.com/file/d/1cnE6YX0_J7uBEhco9kWcPt9eEayOuFiK/view?usp=sharing)

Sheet: Passive Components
Capacitors | Resistors | Inductors

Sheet: Definitions
Name | Definition
Duty Cycle | the percentage of time a signal is ON during one complete cycle
 | Duty Cycle = (Ton / T) x 100%
 | Duty Cycle = (I_typ / I_peak) x 100%
Voltage (V): | the electrical potential difference between two points
 | how much "push" or "pressure" an electric charge feels that makes current flow
 | Water analogy: Water pressure
 | Electrical Meanin: Push that drives electrons through a circuit
Curent (A) | Water analogy: Flow rate (gallons/sec)
 | Electrical meaning: How many electrons move per second
Resistance | Water analogy: Hose Width
 | Electrical meaning: How hard it is for ecltrons to flow
Capacitors | Capacitors are used in circuits for energy storage, smoothing voltage fluctuations
Noise
 | Definition:
 | * Random, broadband, or high-frequency interference riding on the DC voltage.
 | It comes from switching edges, motor commutation, RF coupling, or digital logic.
 | Example:
 | * ESC PWM edges inject short bursts of EMI.
 | * MCU clock harmonics coupling into analog lines.
 | What fixes it:
 | * Ceramic capacitors (1 µF, 0.1 µF) close to pins
 | * Ferrite beads, shielding, ground planes
Ripple
 | Definition:
 | * Periodic voltage variation at a known frequency, caused by switching or rectification.
 | It’s predictable, repeating noise tied to the power conversion process.
 | Example:
 | * Buck converter switching at 500 kHz → produces a 500 kHz sawtooth ripple.
 | * Measured as peak-to-peak (mVpp).
 | What fixes it:
 | * Output capacitors
 | * Low ESR components
 | * LC filters

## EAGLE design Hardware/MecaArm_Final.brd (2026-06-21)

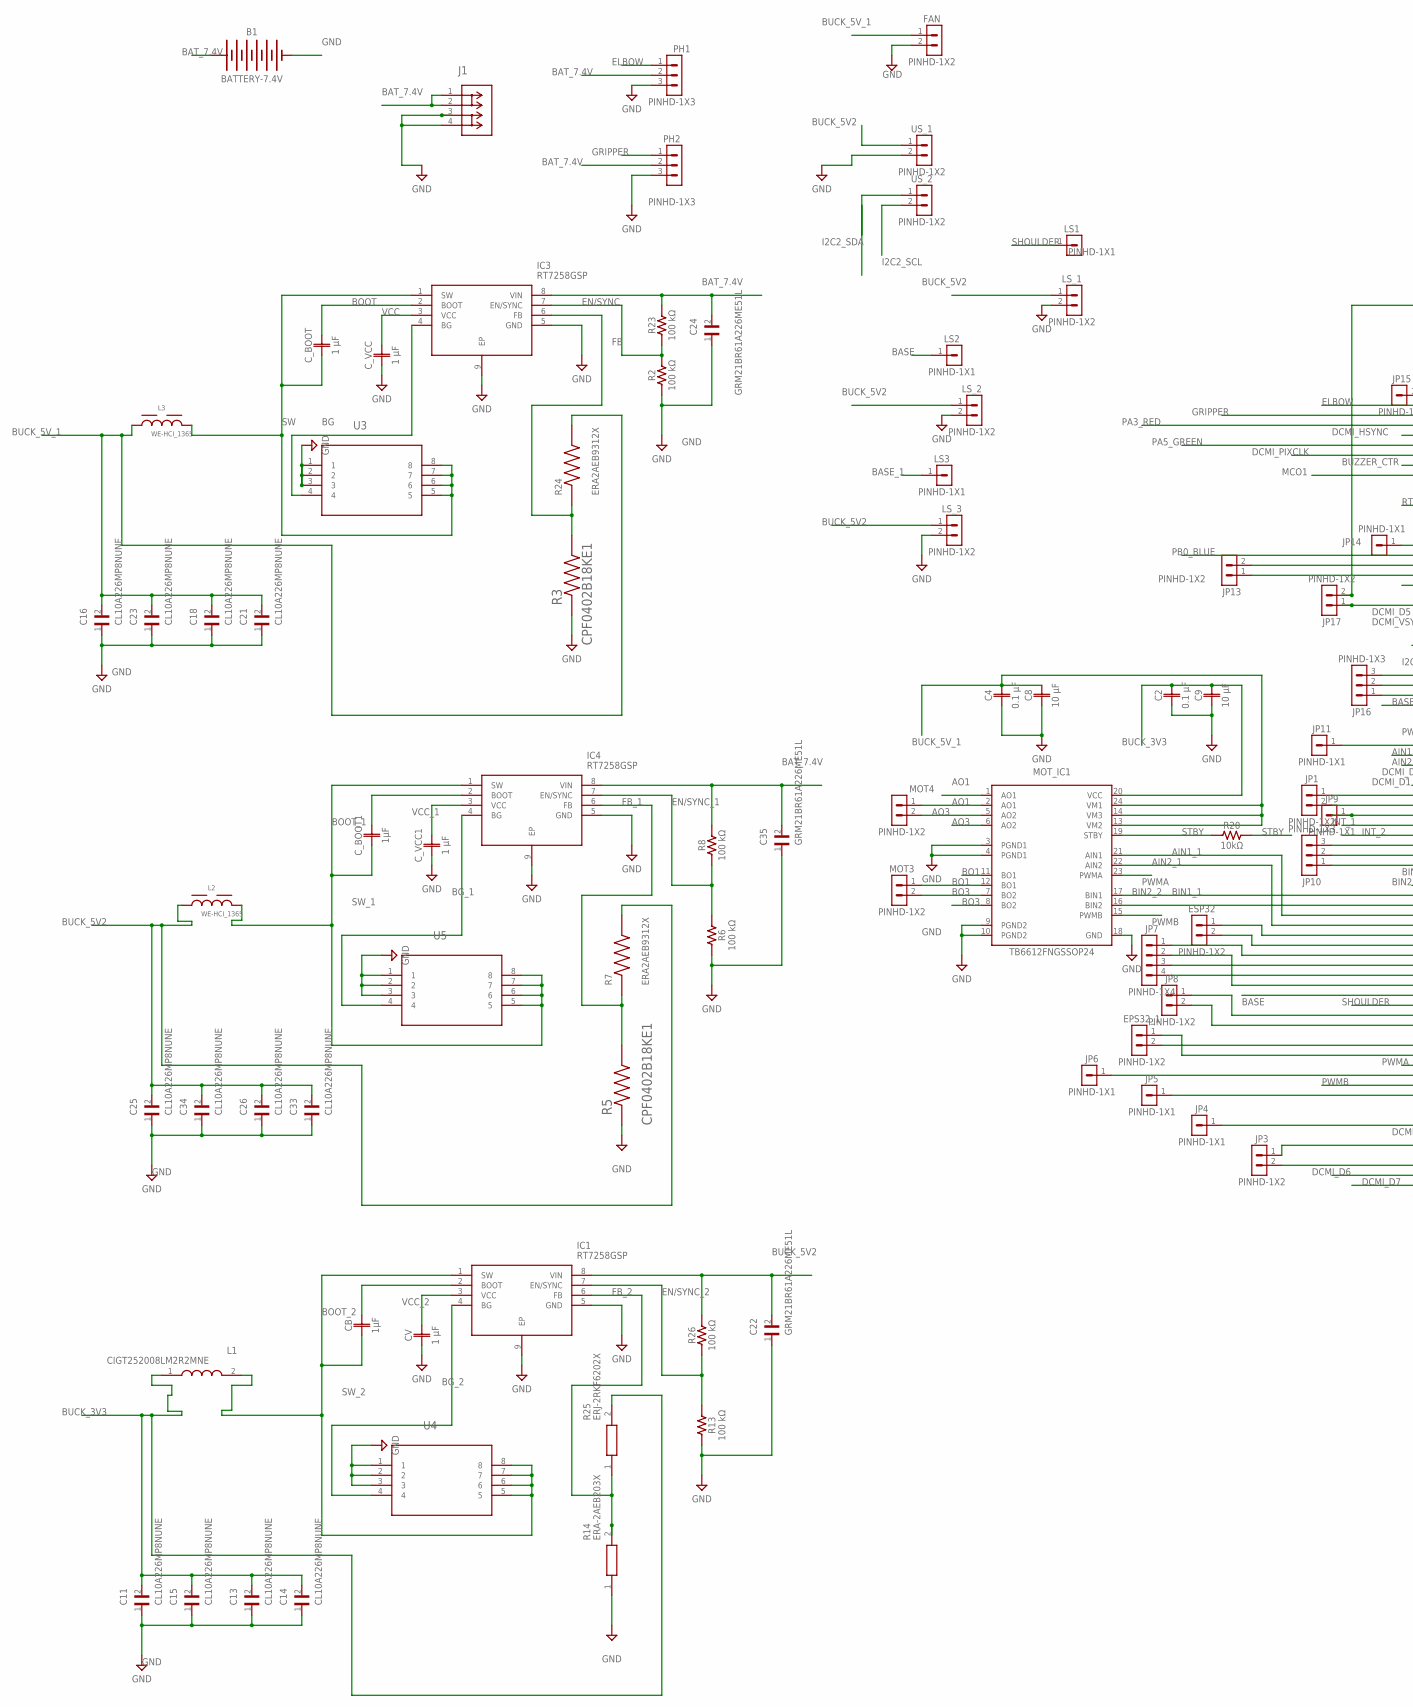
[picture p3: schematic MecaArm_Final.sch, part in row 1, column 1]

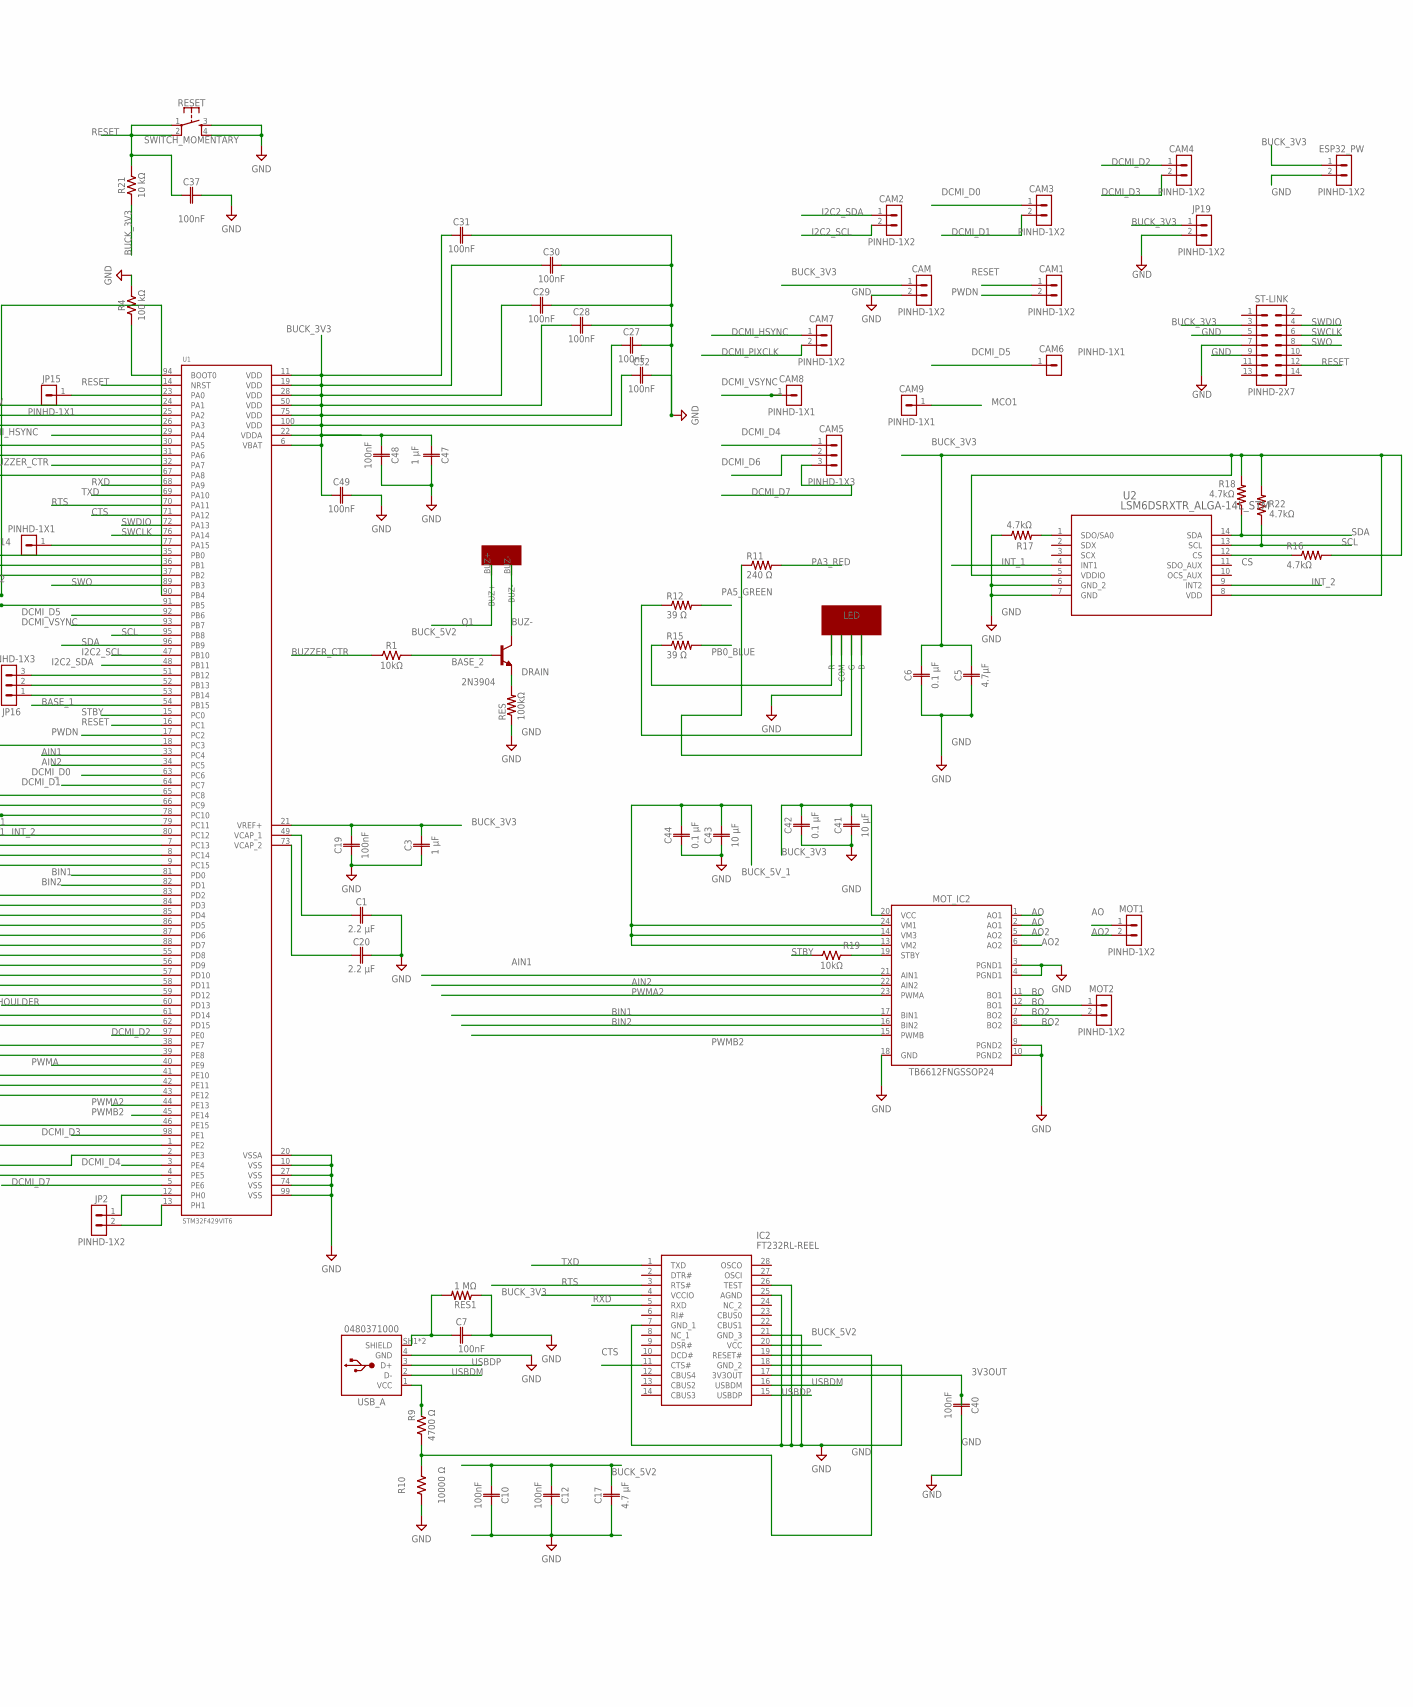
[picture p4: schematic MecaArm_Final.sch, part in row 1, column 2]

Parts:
B1: BATTERY-7.4V; BATTERY-GENERIC
BUZZER: BUZZER_ACTIVE_12X9P5; BUZZER-FOOT
C1, C20: 2.2 µF; CAPC1005X60
C2, C4, C6, C42, C44: 0.1 µF; CAPC1005X60
C3, C47: 1 µF; CAPC1005X60
C5: 4.7µF; CAPC1005X60
C7, C10, C12, C19, C27, C28, C29, C30, C31, C32, C37, C40, C48, C49: 100nF; CAPC1005X60
C8, C9, C41, C43: 10 µF; CAPC1005X60
C11, C13, C14, C15, C16, C18, C21, C23, C25, C26, C33, C34: CL10A226MP8NUNE; CAPC1608X105N
C17: 4.7 μF; CAPC1608X85
C22, C24, C35: GRM21BR61A226ME51L; CAPC2012X140N
CAM, CAM1, CAM2, CAM3, CAM4, CAM7: PINHD-1X2; 1X02
CAM5: PINHD-1X3; 1X03
CAM6, CAM8, CAM9: PINHD-1X1; 1X01
CB: 1µF; CAPC1005X60
CV: 1 µF; CAPC1005X60
C_BOOT: 1 µF; CAPC1005X60
C_BOOT1: 1µF; CAPC1005X60
C_VCC, C_VCC1: 1 µF; CAPC1005X60
EPS32_1: PINHD-1X2; 1X02
ESP32, ESP32_PW: PINHD-1X2; 1X02
FAN: PINHD-1X2; 1X02
IC1, IC3, IC4: RT7258GSP; SOIC127P600X175-9N
IC2: FT232RL-REEL; SOP65P780X200-28N
J1: 1017503CONN_1017491; CONN_1017491
JP1, JP2, JP3, JP8, JP13, JP17, JP19: PINHD-1X2; 1X02
JP4, JP5, JP6, JP9, JP11, JP14, JP15: PINHD-1X1; 1X01
JP7: PINHD-1X4; 1X04
JP10, JP16: PINHD-1X3; 1X03
L1: CIGT252008LM2R2MNE; INDC2520X80N
L2, L3: WE-HCI_1365
LED: LED; LED-FOOT
LS1, LS2, LS3: PINHD-1X1; 1X01
LS_1, LS_2, LS_3: PINHD-1X2; 1X02
MOT1, MOT2, MOT3, MOT4: PINHD-1X2; 1X02
MOT_IC1, MOT_IC2: TB6612FNGSSOP24; SOP65P760X160-24N
PH1, PH2: PINHD-1X3; 1X03
Q1: 2N3904; TO92127P495H495-3
R1: 10kΩ; RESC1005X40
R2, R4, R6, R8, R13, R23, R26: 100 kΩ; RESC1005X40
R3, R5: CPF0402B18KE1; RESC1005X35N
R7, R24: ERA2AEB9312X; RES_ERA2AEB9312X
R9: 4700 Ω; RESC1005X40
R10: 10000 Ω; RESC1005X40
R11: 240 Ω; RESC1005X40
R12, R15: 39 Ω; RESC1005X40
R14: ERA-2AEB203X; ERA2AED122X
R16, R17, R18, R22: 4.7kΩ; RESC1005X40
R19, R20: 10kΩ; RESC2012X65
R21: 10 kΩ; RESC1005X40
R25: ERJ-2RKF6202X; ERJ2RKD1004X
RES: 100kΩ; RESC1005X40
RES1: 1 MΩ; RESC1005X40
RESET: SWITCH_MOMENTARY; SWITCH-MOMENTARY-PTH-6.5MM
ST-LINK: PINHD-2X7; 2X07
U1: STM32F429VIT6; QFP50P1600X1600X160-100N
U2: LSM6DSRXTR_ALGA-14L_STM; LGA-14L_STM
U3, U4, U5: SI7114DN-T1-E3MOSFET_4DN-T1-E3_VIS; MOSFET_4DN-T1-E3_VIS
USB_A: 0480371000
US_1, US_2: PINHD-1X2; 1X02

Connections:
3V3OUT: C40.1, IC2.17 (3V3OUT)
AIN1: MOT_IC2.21 (AIN1), U1.33 (PC4)
AIN1_1: MOT_IC1.21 (AIN1), U1.85 (PD4)
AIN2: MOT_IC2.22 (AIN2), U1.34 (PC5)
AIN2_1: MOT_IC1.22 (AIN2), U1.86 (PD5)
AO: MOT1.1, MOT_IC2.1 (AO1), MOT_IC2.2 (AO1)
AO1: MOT4.1, MOT_IC1.1 (AO1), MOT_IC1.2 (AO1)
AO2: MOT1.2, MOT_IC2.5 (AO2), MOT_IC2.6 (AO2)
AO3: MOT4.2, MOT_IC1.5 (AO2), MOT_IC1.6 (AO2)
BASE: LS2.1, U1.59 (PD12)
BASE_1: LS3.1, U1.54 (PB15)
BASE_2: Q1.2 (B), R1.2
BAT_7.4V: B1.+, C24.2, C35.2, IC3.8 (VIN), IC4.8 (VIN), J1.1, J1.2, PH1.2, PH2.2, R8.2, R23.2
BG: IC3.4 (BG), U3.4
BG_1: IC4.4 (BG), U5.4
BG_2: IC1.4 (BG), U4.4
BIN1: MOT_IC2.17 (BIN1), U1.81 (PD0)
BIN1_1: MOT_IC1.17 (BIN1), U1.83 (PD2)
BIN2: MOT_IC2.16 (BIN2), U1.82 (PD1)
BIN2_2: MOT_IC1.16 (BIN2), U1.84 (PD3)
BO: MOT2.1, MOT_IC2.11 (BO1), MOT_IC2.12 (BO1)
BO1: MOT3.1, MOT_IC1.11 (BO1), MOT_IC1.12 (BO1)
BO2: MOT2.2, MOT_IC2.7 (BO2), MOT_IC2.8 (BO2)
BO3: MOT3.2, MOT_IC1.7 (BO2), MOT_IC1.8 (BO2)
BOOT: C_BOOT.2, IC3.2 (BOOT)
BOOT_1: C_BOOT1.2, IC4.2 (BOOT)
BOOT_2: CB.2, IC1.2 (BOOT)
BUCK_3V3: C2.2, C3.2, C5.2, C6.2, C9.2, C11.2, C13.2, C14.2, C15.2, C19.2, C27.1, C28.1, C29.1, C30.1, C31.1, C32.1, C41.2, C42.2, C49.1, CAM.1, ESP32_PW.1, IC2.4 (VCCIO), JP19.1, L1.1, MOT_IC1.20 (VCC), MOT_IC2.20 (VCC), R16.2, R18.2, R21.1, R22.2, R25.2, ST-LINK.3, U1.6 (VBAT), U1.11 (VDD), U1.19 (VDD), U1.21 (VREF+), U1.28 (VDD), U1.50 (VDD), U1.75 (VDD), U1.100 (VDD), U2.5 (VDDIO), U2.8 (VDD)
BUCK_5V2: BUZZER.BUZ+, C10.1, C12.1, C17.2, C22.2, C25.2, C26.2, C33.2, C34.2, IC1.8 (VIN), IC2.20 (VCC), L2.1, LS_1.1, LS_2.1, LS_3.1, R7.2, R26.2, US_1.1
BUCK_5V_1: C4.2, C8.2, C16.2, C18.2, C21.2, C23.2, C43.2, C44.2, FAN.1, L3.1, MOT_IC1.13 (VM2), MOT_IC1.14 (VM3), MOT_IC1.24 (VM1), MOT_IC2.13 (VM2), MOT_IC2.14 (VM3), MOT_IC2.24 (VM1), R24.2
BUZ-: BUZZER.BUZ-, Q1.3 (C)
BUZZER_CTR: R1.1, U1.32 (PA7)
CS: R16.1, U2.12 (CS)
CTS: IC2.11 (CTS#), U1.71 (PA12)
DCMI_D0: CAM3.1, U1.63 (PC6)
DCMI_D1: CAM3.2, U1.64 (PC7)
DCMI_D2: CAM4.1, U1.97 (PE0)
DCMI_D3: CAM4.2, U1.98 (PE1)
DCMI_D4: CAM5.1, U1.3 (PE4)
DCMI_D5: CAM6.1, U1.92 (PB6)
DCMI_D6: CAM5.2, U1.4 (PE5)
DCMI_D7: CAM5.3, U1.5 (PE6)
DCMI_HSYNC: CAM7.1, U1.29 (PA4)
DCMI_PIXCLK: CAM7.2, U1.31 (PA6)
DCMI_VSYNC: CAM8.1, U1.93 (PB7)
DRAIN: Q1.1 (E), RES.2
ELBOW: PH1.1, U1.24 (PA1)
EN/SYNC: IC3.7 (EN/SYNC), R2.2, R23.1
EN/SYNC_1: IC4.7 (EN/SYNC), R6.2, R8.1
EN/SYNC_2: IC1.7 (EN/SYNC), R13.2, R26.1
FB: IC3.6 (FB), R3.2, R24.1
FB_1: IC4.6 (FB), R5.2, R7.1
FB_2: IC1.6 (FB), R14.2, R25.1
GND: B1.-, C1.2, C2.1, C3.1, C4.1, C5.1, C6.1, C7.2, C8.1, C9.1, C10.2, C11.1, C12.2, C13.1, C14.1, C15.1, C16.1, C17.1, C18.1, C19.1, C20.2, C21.1, C22.1, C23.1, C24.1, C25.1, C26.1, C27.2, C28.2, C29.2, C30.2, C31.2, C32.2, C33.1, C34.1, C35.1, C37.2, C40.2, C41.1, C42.1, C43.1, C44.1, C47.2, C48.2, C49.2, CAM.2, CV.1, C_VCC.1, C_VCC1.1, ESP32_PW.2, FAN.2, IC1.5 (GND), IC1.9 (EP), IC2.7 (GND_1), IC2.18 (GND_2), IC2.21 (GND_3), IC2.25 (AGND), IC2.26 (TEST), IC3.5 (GND), IC3.9 (EP), IC4.5 (GND), IC4.9 (EP), J1.3, J1.4, JP19.2, LED.COM, LS_1.2, LS_2.2, LS_3.2, MOT_IC1.3 (PGND1), MOT_IC1.4 (PGND1), MOT_IC1.9 (PGND2), MOT_IC1.10 (PGND2), MOT_IC1.18 (GND), MOT_IC2.3 (PGND1), MOT_IC2.4 (PGND1), MOT_IC2.9 (PGND2), MOT_IC2.10 (PGND2), MOT_IC2.18 (GND), PH1.3, PH2.3, R2.1, R3.1, R4.2, R5.1, R6.1, R10.1, R13.1, R14.1, R17.1, RES.1, RES1.1, RESET.3, RESET.4, ST-LINK.5, ST-LINK.7, ST-LINK.9, U1.10 (VSS), U1.20 (VSSA), U1.27 (VSS), U1.74 (VSS), U1.99 (VSS), U2.6 (GND_2), U2.7 (GND), U3.1, U3.2, U3.3, U4.1, U4.2, U4.3, U5.1, U5.2, U5.3, USB_A.4 (GND), US_1.2
GRIPPER: PH2.1, U1.25 (PA2)
I2C2_SCL: CAM2.2, U1.47 (PB10), US_2.2
I2C2_SDA: CAM2.1, U1.48 (PB11), US_2.1
INT_1: U1.79 (PC11), U2.4 (INT1)
INT_2: U1.80 (PC12), U2.9 (INT2)
MCO1: CAM9.1, U1.67 (PA8)
unnamed: R4.1, U1.94 (BOOT0)
unnamed: JP2.2, U1.13 (PH1)
unnamed: C20.1, U1.73 (VCAP_2)
unnamed: C47.1, C48.1, U1.22 (VDDA)
unnamed: C1.1, U1.49 (VCAP_1)
unnamed: JP2.1, U1.12 (PH0)
unnamed: JP3.1, U1.1 (PE2)
unnamed: JP3.2, U1.2 (PE3)
unnamed: JP4.1, U1.46 (PE15)
unnamed: JP5.1, U1.43 (PE12)
unnamed: JP6.1, U1.41 (PE10)
unnamed: EPS32_1.2, U1.38 (PE7)
unnamed: EPS32_1.1, U1.39 (PE8)
unnamed: JP8.1, U1.61 (PD14)
unnamed: JP8.2, U1.62 (PD15)
unnamed: ESP32.1, U1.87 (PD6)
unnamed: ESP32.2, U1.88 (PD7)
unnamed: JP7.1, U1.55 (PD8)
unnamed: JP7.3, U1.56 (PD9)
unnamed: JP7.4, U1.57 (PD10)
unnamed: JP7.2, U1.58 (PD11)
unnamed: JP1.1, U1.65 (PC8)
unnamed: JP1.2, U1.66 (PC9)
unnamed: JP9.1, U1.78 (PC10)
unnamed: JP10.3, U1.7 (PC13)
unnamed: JP10.2, U1.8 (PC14)
unnamed: JP10.1, U1.9 (PC15)
unnamed: JP11.1, U1.18 (PC3)
unnamed: JP16.3, U1.51 (PB12)
unnamed: JP16.2, U1.52 (PB13)
unnamed: JP16.1, U1.53 (PB14)
unnamed: JP13.2, U1.36 (PB1)
unnamed: JP13.1, U1.37 (PB2)
unnamed: JP17.2, U1.90 (PB4)
unnamed: R9.2, USB_A.1 (VCC)
unnamed: JP17.1, U1.91 (PB5)
unnamed: JP14.1, U1.77 (PA15)
unnamed: JP15.1, U1.23 (PA0)
PA3_RED: R11.2, U1.26 (PA3)
PA5_GREEN: R12.2, U1.30 (PA5)
PB0_BLUE: R15.2, U1.35 (PB0)
PE13: LED.R, R15.1
PE15: LED.G, R12.1
PE16: LED.B, R11.1
PWDN: CAM1.2, U1.17 (PC2)
PWMA: MOT_IC1.23 (PWMA), U1.40 (PE9)
PWMA2: MOT_IC2.23 (PWMA), U1.44 (PE13)
PWMB: MOT_IC1.15 (PWMB), U1.42 (PE11)
PWMB2: MOT_IC2.15 (PWMB), U1.45 (PE14)
RESET: C37.1, CAM1.1, R21.2, RESET.1, RESET.2, ST-LINK.12, U1.14 (NRST), U1.16 (PC1)
RTS: IC2.3 (RTS#), IC2.19 (RESET#), R9.1, R10.2, U1.70 (PA11)
RXD: IC2.5 (RXD), U1.68 (PA9)
SCL: R22.1, U1.95 (PB8), U2.13 (SCL)
SDA: R18.1, U1.96 (PB9), U2.14 (SDA)
SDO/SA0: R17.2, U2.1 (SDO/SA0)
SHIELD: C7.1, RES1.2, USB_A.SH1 (SHIELD), USB_A.SH2 (SHIELD)
SHOULDER: LS1.1, U1.60 (PD13)
STBY: MOT_IC1.19 (STBY), MOT_IC2.19 (STBY), R19.1, R19.2, R20.1, R20.2, U1.15 (PC0)
SW: C_BOOT.1, IC3.1 (SW), L3.2, U3.5, U3.6, U3.7, U3.8
SWCLK: ST-LINK.6, U1.76 (PA14)
SWDIO: ST-LINK.4, U1.72 (PA13)
SWO: ST-LINK.8, U1.89 (PB3)
SW_1: C_BOOT1.1, IC4.1 (SW), L2.2, U5.5, U5.6, U5.7, U5.8
SW_2: CB.1, IC1.1 (SW), L1.2, U4.5, U4.6, U4.7, U4.8
TXD: IC2.1 (TXD), U1.69 (PA10)
USBDM: IC2.16 (USBDM), USB_A.2 (D-)
USBDP: IC2.15 (USBDP), USB_A.3 (D+)
VCC: C_VCC.2, IC3.3 (VCC)
VCC_1: C_VCC1.2, IC4.3 (VCC)
VCC_2: CV.2, IC1.3 (VCC)

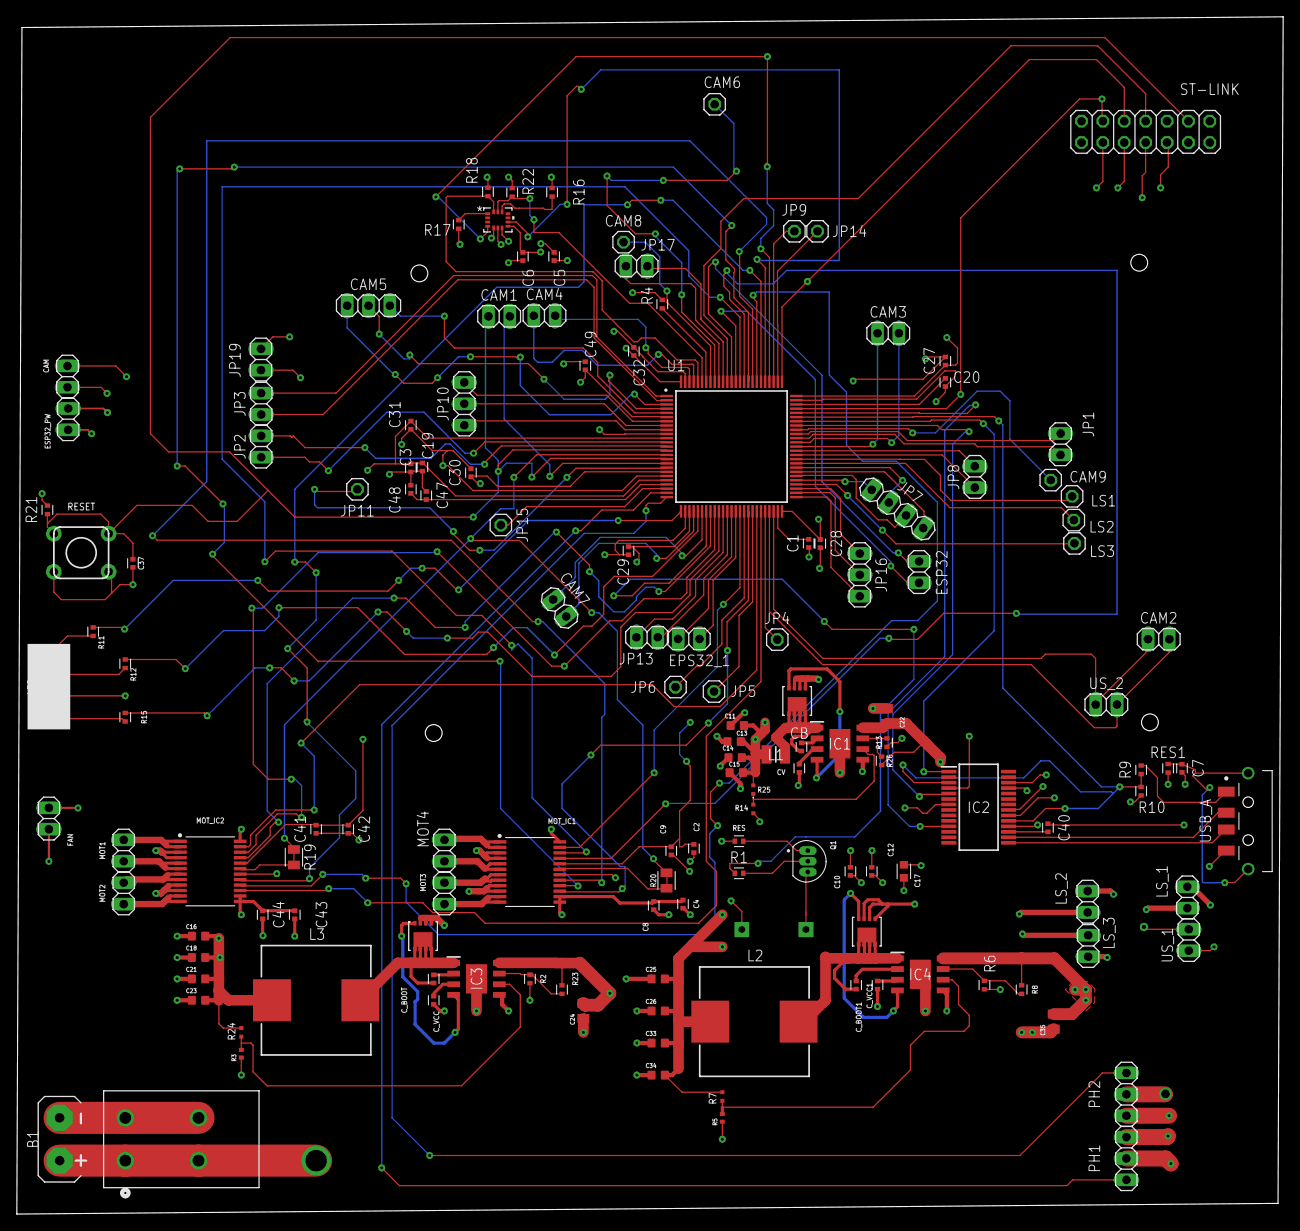
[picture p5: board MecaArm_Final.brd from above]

Board: 4 copper layers, 150.4 x 142.2 mm, 145 parts (1 on the bottom side), 130 nets.

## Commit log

2025-12-25 Rename Screenshot 2025-12-25 131624.png to layout/pcb_top.png
2025-12-25 Rename Screenshot 2025-12-25 131707.png to layout/pcb_bottom.png

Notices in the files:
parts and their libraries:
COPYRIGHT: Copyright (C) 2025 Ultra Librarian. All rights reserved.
